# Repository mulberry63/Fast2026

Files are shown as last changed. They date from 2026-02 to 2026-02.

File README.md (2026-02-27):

# 🚁 Fast2026 - 中控杯

本项目旨在从零自主搭建一台具备自动导航与目标抓取能力的空中机器人（无人机），涵盖机械设计、硬件装配、ROS底层驱动与上层状态机算法。

---

## 🎯 项目核心任务分解

### 1. 🛠️ 无人机基础装配与试飞
- [ ] 根据装配文档（见 `docs/` 目录）完成飞机底盘拼装。
- [ ] 飞控参数配置，实现稳定可靠的手动遥控飞行。

### 2. 📡 机载设备部署与自动导航
- [ ] 挂载激光雷达与机载电脑。
- [ ] 烧录现有程序与环境配置。
- [ ] 实现无人机点到点的自主导航飞行。

### 3. ⚙️ 机械夹爪自主设计
- [ ] 根据抓取目标物，完成夹爪的 3D CAD 建模。

### 4. 🔌 夹爪舵机驱动开发
- [ ] 编写底层的舵机控制代码。
- [ ] 封装为 ROS 节点，实现通过 ROS 话题/服务控制夹爪开闭。

### 5. 🧠 系统集成与总控状态机
- [ ] 将夹爪节点接入现有 ROS 导航工作空间。
- [ ] 编写总控状态机

---

## 💻 团队协作指南 (Git 工作流)

为了避免文件冲突和代码丢失，请团队成员严格遵循以下步骤：

### 📥 1. 初次下载仓库 (Clone)
如果你是第一次参与项目，请打开终端（或 CMD）将云端代码下载到本地：
```bash
git clone https://github.com/你的用户名/Fast2026.git
```

### 🔄 2. 每日干活铁律 (Pull)
**⚠️ 警告：每次开始修改文件或写代码前，第一件事永远是更新代码！**
在 `Fast2026` 文件夹下打开终端，运行：
```bash
git pull
```

### 📤 3. 提交你的工作成果 (Add / Commit / Push)
当你在本地完成了某个文档修改、CAD模型更新或代码编写后，执行以下“三板斧”上传到云端：

```bash
# 第一步：把所有修改过、新增的文件暂存起来 (注意 add 后面的空格和点)
git add .

# 第二步：写下本次更新的备注留言 (请简明扼要，如"新增夹爪V1版打印文件")
git commit -m "在这里写你的修改备注"

# 第三步：推送到云端仓库
git push
```

---
**💡 小贴士：**
* 机械组同学提交 CAD 模型时，请**务必同时导出 STL/STEP 格式**，方便未安装 CAD 软件的同学预览。
* 代码组同学在 `ros_ws/` 中写代码时，**绝对不要**把 `build/` 和 `devel/` 文件夹传上来（项目已配置好 `.gitignore` 自动屏蔽）。
```

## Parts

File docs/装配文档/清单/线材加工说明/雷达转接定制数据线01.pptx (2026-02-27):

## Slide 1

SH1.0-12p -> GH1.25-4p雷达网线 适用DM载板v1.1-fast雷达转接板

SH1.0mm 12Pin 端

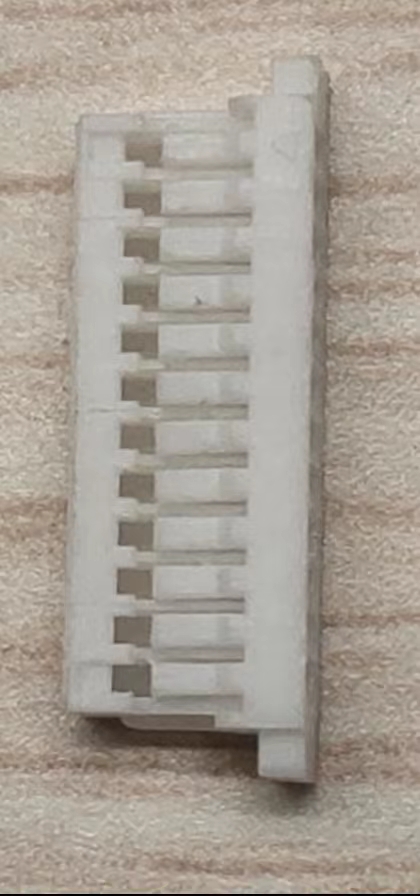
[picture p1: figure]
SH1.0mm 12P 胶壳

GH1.25mm 4Pin 端

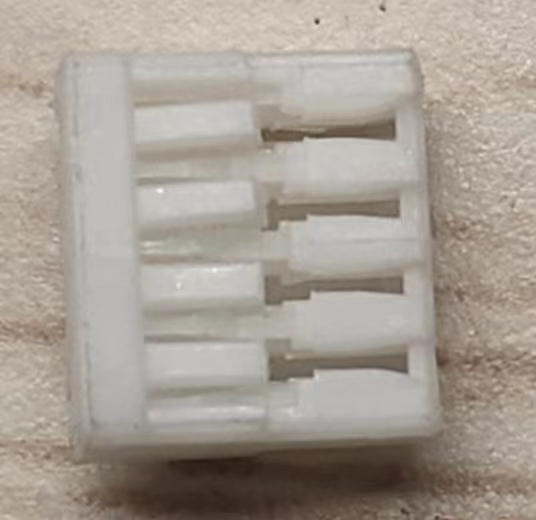
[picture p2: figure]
GH1.25mm 1x4P 压线端子胶壳

线长15cm，线材使用软硅胶线，线色如图 ，30根

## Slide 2

SH1.0-8p -> GH1.25-4p雷达网线 适用DM载板v2.0-fast雷达转接板

SH1.0mm 8Pin 端

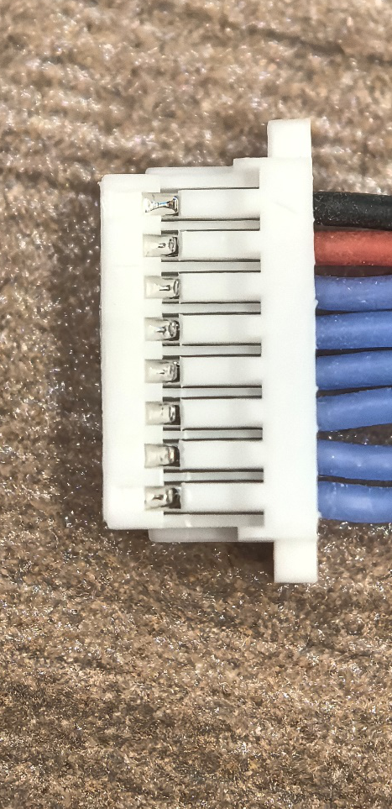
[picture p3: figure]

GH1.25mm 4Pin 端

线长15cm，线材使用软硅胶线，线色如图

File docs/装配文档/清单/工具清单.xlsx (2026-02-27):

序号 | 名称 | 规格 | 备注（如有，特殊要求） | 下单链接
1 | 航空箱 | 定制 |  | https://item.taobao.com/item.htm?from=cart&id=655358936203&skuId=4909482691266
2 | 拉杆工具箱 | 品牌同款拉杆箱大号-绿色 四层工具板 |  | https://item.taobao.com/item.htm?from=cart&id=709059705581&skuId=5535688010904
3 | 批头 | GSH025S 2.5x65mm内六角 |  | https://item.taobao.com/item.htm?id=596181686009&from=cart&skuId=4309524610184
4 | 批头 | GS5P-32 150mm长5支装 |  | https://item.taobao.com/item.htm?id=596181686009&from=cart&skuId=4309524610203
5 | 批头 | GS5P-31 65mm长5支装 |  | https://item.taobao.com/item.htm?id=596181686009&from=cart&skuId=4309524610202
6 | 批头 | GSH015S 1.5x65mm内六角 |  | https://item.taobao.com/item.htm?id=596181686009&from=cart&skuId=4309524610183
7 | RC遥控模型车内六角螺丝刀十字一字六角套筒6.35mm航模工具套装 (https://item.taobao.com/item.htm?id=762095687046&from=cart&skuId=5249389084331) | 内六角4合一套装 |  | https://item.taobao.com/item.htm?id=762095687046&from=cart&skuId=5249389084331
8 | SATA世达棘轮扳手套筒组合套装小飞/中飞/大飞汽修车工具专用全套 (https://item.taobao.com/item.htm?id=782432810657&from=cart&skuId=5512006822639) | 小飞套筒组套【36件】09001 |  | https://item.taobao.com/item.htm?id=782432810657&from=cart&skuId=5512006822639
9 | 开拓迷你开口梅花两用扳手套装组合大全小号螺母全英制一整成套 (https://item.taobao.com/item.htm?id=540861523658&from=cart&skuId=4961793017982) | 公制开口梅花迷你5件套（4-4.5-5-5.5-6mm） |  | https://item.taobao.com/item.htm?id=540861523658&from=cart&skuId=4961793017982
10 | 超薄款双头开口扳手 | 超薄款梅开两用扳手4mm |  | https://detail.tmall.com/item.htm?id=851356332552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
11 | 博世手动螺丝刀46件26件套棘轮内六角套筒十字螺丝批组合工具套装 (https://item.taobao.com/item.htm?id=763569830538&from=cart&skuId=5258953145313) | 26件套棘轮扳手批头 |  | https://item.taobao.com/item.htm?id=763569830538&from=cart&skuId=5258953145313
12 | 日本福冈内六角套装s2加长款6角梅花螺丝刀小t型折叠六棱扳手工具 (https://item.taobao.com/item.htm?id=676218849401&from=cart&skuId=4857481332285) | FO-3301A【中长球头平头9件套】 性价比推荐 |  | https://item.taobao.com/item.htm?id=676218849401&from=cart&skuId=4857481332285
13 | 电钻 | 棘轮冲击款【2.0Ah两电一充】+全套礼包 |  | https://item.taobao.com/item.htm?id=728453365825&from=cart&skuId=5823571047206
14 | 世达螺丝刀十字一字小高硬度工具梅花起子小型平口改锥带强磁套装 (https://item.taobao.com/item.htm?id=759865044572&from=cart&skuId=5407968842822) | 【十字】3x75mm/62302 |  | https://item.taobao.com/item.htm?id=759865044572&from=cart&skuId=5407968842822
15 | 世达螺丝刀十字一字小高硬度工具梅花起子小型平口改锥带强磁套装 | 【一字】3x75mm/62202 |  | https://item.taobao.com/item.htm?id=759865044572&from=cart&skuId=5407968842823
16 | 美国EDS-110991 公制内六角工具套裝 4支1.5 2.0 2.5 3.0X120现货 (https://item.taobao.com/item.htm?id=522870804348&from=cart&skuId=3171451899987) | 整套4把（EDS-110991） |  | https://item.taobao.com/item.htm?id=522870804348&from=cart&skuId=3171451899987
17 | 镊子 | 【安立信】高精密不锈钢 六件套（AT-10、11、12、13、14、15）送收纳盒 |  | https://detail.tmall.com/item.htm?from=cart&id=854938114743&skuId=5999010703984
18 | 日本福冈水口钳偏口钳子模型小剪钳口水剪德国进口电工专用斜口钳 (https://item.taobao.com/item.htm?id=572377244946&from=cart&skuId=3968092274861) | 7寸水口钳FO-1117 |  | https://item.taobao.com/item.htm?id=572377244946&from=cart&skuId=3968092274861
19 | 鹏工薄壁外六角套筒螺丝刀电脑组装薄套筒起子外六角螺母深套筒批 (https://item.taobao.com/item.htm?id=585503044239&from=cart&skuId=4138388982041) | 5.5mm单支 |  | https://item.taobao.com/item.htm?id=585503044239&from=cart&skuId=4138388982041
20 | 鹏工薄壁外六角套筒螺丝刀电脑组装薄套筒起子外六角螺母深套筒批 (https://item.taobao.com/item.htm?id=585503044239&from=cart&skuId=4138388982042) | 4.0mm单支 |  | https://item.taobao.com/item.htm?id=585503044239&from=cart&skuId=4138388982042
21 | 钢拓活动棘轮扳手快速扳手双头双向梅花开口汽修活头两用扳手工具 (https://item.taobao.com/item.htm?id=574692714560&from=cart&skuId=5802478869891) | 13mm活动棘轮 |  | https://item.taobao.com/item.htm?id=574692714560&from=cart&skuId=5802478869891
22 | 钢拓活动棘轮扳手快速扳手双头双向梅花开口汽修活头两用扳手工具 (https://item.taobao.com/item.htm?id=574692714560&from=cart&skuId=5802478869899) | 8mm活动棘轮 |  | https://item.taobao.com/item.htm?id=574692714560&from=cart&skuId=5802478869899
23 | 绿林水口钳高达模型剪钳斜口钳口水钳日本德国电工进口线偏口钳子 (https://item.taobao.com/item.htm?id=636927035616&from=cart&skuId=4792100687124) | 【匠心质造】5寸日式水口钳-超薄款【模型推荐】 |  | https://item.taobao.com/item.htm?id=636927035616&from=cart&skuId=4792100687124
24 | 绿林针嘴钳尖嘴钳电工专用小钳子大全尖头钳多功能尖嘴钳子手工用 (https://item.taobao.com/item.htm?id=732723065228&from=cart&skuId=5069822680654) | 迷你针嘴钳150mm |  | https://item.taobao.com/item.htm?id=732723065228&from=cart&skuId=5069822680654
25 | 绿林L型套筒扳手工具六角烟斗7字型弯头双头穿孔轮胎扳手6-19mm (https://item.taobao.com/item.htm?id=558244068545&from=cart&skuId=4819402215447) | 加长L型扳手13mm |  | https://item.taobao.com/item.htm?id=558244068545&from=cart&skuId=4819402215447
26 | 绿林针嘴钳尖嘴钳电工专用小钳子大全尖头钳多功能尖嘴钳子手工用 (https://item.taobao.com/item.htm?id=732723065228&from=cart&skuId=5069822680660) | 迷你尖嘴钳125mm |  | https://item.taobao.com/item.htm?id=732723065228&from=cart&skuId=5069822680660
27 | 绿林碳纤维卡尺高精度数显游标卡尺玻璃栅电子卡尺不锈钢数字测量 (https://item.taobao.com/item.htm?id=766044927383&from=cart&skuId=5268275533110) | 【0-150mm】【20年寿命玻璃栅款】【碳纤维升级】 |  | https://item.taobao.com/item.htm?id=766044927383&from=cart&skuId=5268275533110
28 | CFORCE便携显示器4k触控144hz扩展屏笔记本电脑副屏switch外接屏 (https://item.taobao.com/item.htm?id=605670886301&from=cart&skuId=5967632443268) | 15.6寸【120Hz办公16Plus】2.5K超清/IPS护眼/100%sRGB色域/送保护皮套 |  | https://item.taobao.com/item.htm?id=605670886301&from=cart&skuId=5967632443268
29 | 友邦焊锡丝 高纯度 流动性好 活性锡线Sn63PbA 63%含锡量 松香芯 (https://item.taobao.com/item.htm?id=43741015860&from=cart&skuId=79364921499) | Sn63PbA 1.0mm线径（净重100克） |  | https://item.taobao.com/item.htm?id=43741015860&from=cart&skuId=79364921499
30 | 日本福冈尖嘴钳进口 德国技术多功能尖头 尖咀钳6寸钓鱼钳子专用 (https://item.taobao.com/item.htm?id=521588031533&from=cart&skuId=3955094443294) | 2605欧式尖嘴钳8寸（送电笔） |  | https://item.taobao.com/item.htm?id=521588031533&from=cart&skuId=3955094443294
31 | 日本tajima田岛美工刀重型全钢加厚壁纸刀刀架 (https://item.taobao.com/item.htm?id=36632336125&from=cart&skuId=4914053270244) | 中号18mm款/旋钮锁 AC501B |  | https://item.taobao.com/item.htm?id=36632336125&from=cart&skuId=4914053270244
32 | 得力双头油性记号笔黑色勾线笔快干防水美术专用小学生防油不掉色 (https://item.taobao.com/item.htm?id=794834842303&from=cart&skuId=5426482581983) | 【黑色】双头12支 / 6823（1盒） |  | https://item.taobao.com/item.htm?id=794834842303&from=cart&skuId=5426482581983
33 | 剪刀 | 中号+大号/各1把黄色（发黑防锈） |  | https://item.taobao.com/item.htm?id=638671987627&from=cart&skuId=5046922966914
34 | VESSEL内六角批头日本进口威威六角批头加长电动圆头六方风批强磁 (https://item.taobao.com/item.htm?id=654440293673&from=cart&skuId=5695207560125) | 5孔批头夹（蓝色）(BH-05N) |  | https://item.taobao.com/item.htm?id=654440293673&from=cart&skuId=5695207560125
35 | 焊台 | 标配+3种烙铁头（T12-K头+T12-Ku头+T12-BC3头） |  | https://item.taobao.com/item.htm?id=609759063116&from=cart&skuId=5099730029461
36 | 日本福冈进口多功能钢丝钳老虎钳子拉线钳电工专用特种钢手钳德国 (https://item.taobao.com/item.htm?id=564658222984&from=cart&skuId=3641967885881) | FO-1302钢丝钳（7寸拉线款） |  | https://item.taobao.com/item.htm?id=564658222984&from=cart&skuId=3641967885881
37 | 日本福冈专用钢丝钳特种老虎钳多功能尖嘴钳工业级斜嘴钳电工套装 (https://item.taobao.com/item.htm?id=564165540337&from=cart&skuId=4580939465805) | FO-1304尖嘴钳【6寸】新款 |  | https://item.taobao.com/item.htm?id=564165540337&from=cart&skuId=4580939465805
38 | 绿联micro hdmi转hdmi线连接转接小头采集卡高清直播适用索尼相机 (https://item.taobao.com/item.htm?id=37607334919&from=cart&skuId=5607363026888) | 【稳定转换高清大屏】4K/60Hz高清-加厚PVC，1.5米 |  | https://detail.tmall.com/item.htm?from=cart&id=37607334919&skuId=5607363026888
39 | 绿联拓展坞typec扩展hdmi投屏转换usb分线器hub集线网线多接口转接头适用华为苹果雷电4笔记本电脑iPad11平板 | 【4合1】USB3.0x3+千兆网口 |  | https://detail.tmall.com/item.htm?from=cart&id=628685171247&skuId=5324107194639
40 | 扎带 | 15公分长丨白色细款丨100根/包 |  | https://item.taobao.com/item.htm?id=729697526781&from=cart&skuId=5920985002019
41 | HDMI接口to转 Mini Micro 高清 单反 相机 监视器 4K 弹簧线 短线 (https://item.taobao.com/item.htm?id=599378064489&from=cart&skuId=4529987314852) | 【4K 极细版】HDMI转D型（Micro HDMI） 直对直 |  | https://detail.tmall.com/item.htm?from=cart&id=599378064489&skuId=4529987314852
42 | 德力西电气145合一精工螺丝刀组套设备拆装S2+CRV钢强磁吸附套装 (https://item.taobao.com/item.htm?id=846600045464&from=cart&skuId=5627821992278) | 145合一螺丝刀套装 |  | https://item.taobao.com/item.htm?id=846600045464&from=cart&skuId=5627821992278
43 | 黑色醋酸胶带耐高温绝缘胶带排线束捆扎手机电视屏幕液晶维修胶布 (https://item.taobao.com/item.htm?id=38441542800&from=cart&skuId=51831447403) | 30MM宽*30M长 |  | https://item.taobao.com/item.htm?id=38441542800&from=cart&skuId=51831447403
44 | 黑色醋酸胶带耐高温绝缘胶带排线束捆扎手机电视屏幕液晶维修胶布 (https://item.taobao.com/item.htm?id=38441542800&from=cart&skuId=51831447403) | 20MM宽*30M长常用款 |  | https://item.taobao.com/item.htm?id=38441542800&from=cart&skuId=51831447399
45 | 12V 6A 72W电源适配器24v 5A 100W适合B6 Q6 M6 M7平衡充电器供电 (https://item.taobao.com/item.htm?id=44358580335&from=cart&skuId=4783448933220) | 12V 6A【DC5.5插头】安全功率60W |  | https://item.taobao.com/item.htm?id=44358580335&from=cart&skuId=4783448933220
46 | Updown露营车手推车营地拖车户外可折叠野营小拉车野餐车儿童可躺 (https://item.taobao.com/item.htm?id=735036772871&from=cart&skuId=5871039130680) | ⭐店长推荐【坦克款/曜石黑】+升级可折叠桌板 |  | https://item.taobao.com/item.htm?id=735036772871&from=cart&skuId=5871039130680
47 | XT60 XT30 T插母头转DC5.5*2.1/2.5mm母头视频眼镜电池充电转接线 (https://item.taobao.com/item.htm?id=831186088302&from=cart&skuId=5568304736538) | DC5.5*2.5母转XT30母 |  | https://item.taobao.com/item.htm?id=831186088302&from=cart&skuId=5568304736538
48 | 3m双面胶贴强力粘胶海绵胶带汽车车用VHB防水无痕高粘度固定墙面 (https://item.taobao.com/item.htm?id=592230232424&from=cart&skuId=5249613279075) | 【升级 2卷】1厘米宽*3米 |  | https://item.taobao.com/item.htm?id=592230232424&from=cart&skuId=5249613279075
49 | 3m双面胶贴强力粘胶海绵胶带汽车车用VHB防水无痕高粘度固定墙面 (https://item.taobao.com/item.htm?id=592230232424&from=cart&skuId=4252197123714) | 3厘米宽*3米长【升级版】 |  | https://item.taobao.com/item.htm?id=592230232424&from=cart&skuId=4252197123714
50 | 扎带 | 3*200宽2.5白100条 |  | https://item.taobao.com/item.htm?id=839224689390&from=cart&skuId=5600725460192
51 | 扎带 | 3*100宽2.5黑100条 |  | https://item.taobao.com/item.htm?id=839224689390&from=cart&skuId=5600725460186
52 | 德力西万用表电工专用维修数字高精度万能表全自动智能防烧890D/C (https://item.taobao.com/item.htm?id=709886959523&from=cart&skuId=4975474060765) | 890D+升级【赠鳄鱼夹+电池+表笔+保险管】 |  | https://item.taobao.com/item.htm?id=709886959523&from=cart&skuId=4975474060765
53 | 卡夫特502GP胶水正品瞬干胶粘金属铁塑料快干速干多功能粘得牢瞬间胶粘鞋补鞋专用焊接剂强力万能胶水 | 502GP 2支【划算】 |  | https://item.taobao.com/item.htm?id=584458030809&from=cart&skuId=5529823123973
54 | SMA小辣椒GPS1.2Ｇ1.4Ｇ1.5G-5Ｇ5.8ＧHz315mhz433/GPS/4G/5G天线 | SMA直黑套 公头内针 | 拍下备注 频率1410mhz-1470mhz | https://item.taobao.com/item.htm?abbucket=17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
55 | MMCX转SMA馈线 | MMCX弯头转SMA内孔，100mm长 |  | https://item.taobao.com/item.htm?from=cart&id=615078294038&skuId=4501459182444
56 | 德力西强力吸锡器吸锡泵电子拆焊清除锡渣焊锡工具手动真空吸锡枪 | 【紧密自动回弹款单支装】半铝强力吸锡器（防静电+耐高温） |  | https://item.taobao.com/item.htm?id=765881479108&from=cart&skuId=5267752237089
57 | 德力西钢卷尺5米家用不锈钢米尺高精度圈尺加厚加硬拉尺10米尺子 (https://item.taobao.com/item.htm?id=704061414618&from=cart&skuId=4957646261617) | 【德力西】7.5米*25mm加宽尺带-不锈钢尺带-激光刻度 |  | https://item.taobao.com/item.htm?id=704061414618&from=cart&skuId=4957646261617
58 | 德力西棘轮扳手快速梅花开口自动双向万能两用梅开板手工具套装 (https://item.taobao.com/item.htm?id=682984862384&from=cart&skuId=4883045608286) | 德力西加长-13mm【用坏换新】送手套 |  | https://item.taobao.com/item.htm?id=682984862384&from=cart&skuId=4883045608286

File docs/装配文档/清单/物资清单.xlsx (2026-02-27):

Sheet: Sheet1
物资清单
序号 | 名称 | 数量 | 购买链接 | 备注
 | 碳板 | 1 |  | 图纸和加工说明见碳板文件夹
 | 雷达保护罩 | 1
 | livox mid 360 | 1
 | 微空飞塔（nxtpx4+50A） | 1 | https://e.tb.cn/h.6zjjxA4rLb3XZSN?tk=lh0YVpP3kD9 CZ225
 | 电池（21700-6s1p） | 2 | 定制21700 40T大功率航模植保机飞行机25.2v6S1P动力锂电池组-淘宝网 (https://item.taobao.com/item.htm?app=chrome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)
 | 分电板 | 1
 | 7037桨叶（PC桨叶 乾丰7037） | 4 | https://item.taobao.com/item.htm?abbucket=20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
 | BB响 | 1 | 电池航模遥控飞机1-8S高精度电量显示器低压报警器双功能BB响电显-淘宝网 (https://item.taobao.com/item.htm?ali_trackid=282_6f4573d720882b9794d1c7404aa6e142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)
 | 接收器 | 1 | https://item.taobao.com/item.htm?id=615817018031&skuId=5969046851703
 | AT9SPRO遥控器 | 1 | 乐迪 AT9S 航模遥控器多轴直升机固定翼PRO无人机2.4G中文模型AT9-淘宝网 (taobao.com) (https://item.taobao.com/item.htm?detail_redpacket_pop=true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)
 | 遥控器电池 | 1 | 乐迪AT9S/AT10/天地飞9遥控器控电 3s 11.1v 2200mAh 8C锂电池-淘宝网 (taobao.com) (https://item.taobao.com/item.htm?_u=a20mja9h57be&id=529555323423&skuId=3472562656133)
 | 优象光流（UP-T101-Plus-PX4） | 1 | UP-T101-Plus光流模块激光测距一体模组4米激光-淘宝网 (taobao.com) (https://item.taobao.com/item.htm?from=cart&id=737685317693&skuId=5486536996319)
 | NX核心板 |  | Jetson Orin NX 16GB 模组 核心板 orin nano agx orin Xavier-tmall.com天猫 (https://detail.tmall.com/item.htm?from=cart&id=699184482674&skuId=5113558482139)
 | NX散热大风扇 | 1 | https://e.tb.cn/h.6BrOpWUDVmbMGot?tk=A6gvVLE5WGd HU287
 | 网卡天线 |  | 2.4g wifi内置FPC软天线5G 5.8G双频PCB贴片ZigBee蓝牙全向高增益-淘宝网 (https://item.taobao.com/item.htm?from=cart&id=586127342811&skuId=4017577965391)
 | 达妙V2载板+256G硬盘+网卡 | 1 | https://e.tb.cn/h.6BG78LJdOkJnq3O?tk=FqsiVLEaQj8 CZ321
 | USB相机90度 uvc相机 90°视场角无畸变 3.24mm焦距 30fps-120fps | 1 | 200万像素1080P高清USB摄像头模组120帧高帧率UVC免驱动鱼眼广角-tmall.com天猫 (https://detail.tmall.com/item.htm?app=chrome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)
 | USB相机120度（uvc相机 120°视场角微畸变 1.8mm焦距 30fps-120fps） | 1 | 200万像素1080P高清USB摄像头模组120帧高帧率UVC免驱动鱼眼广角-tmall.com天猫 (https://detail.tmall.com/item.htm?app=chrome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)
 | Tmotor f90 1300kv | 4 | https://item.taobao.com/item.htm?abbucket=20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
 | 螺丝M3*14（50个） | 2 | https://item.taobao.com/item.htm?id=598485951777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
 | 单头铝柱M3*18+4 (10个) | 1 | https://detail.tmall.com/item.htm?from=cart&id=798703064988&skuId=5617287975848
 | 铝柱M3*20（5个） | 2 | https://detail.tmall.com/item.htm?from=cart&id=719358549398&skuId=5189006551294
 | 铝柱M3*30（5个） | 2 | https://detail.tmall.com/item.htm?from=cart&id=719358549398&skuId=5189006551294
 | 螺丝M2*8 | 1 | https://detail.tmall.com/item.htm?id=631928248397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
 | 螺丝M2*6 | 1 | https://detail.tmall.com/item.htm?id=631928248397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
 | 螺丝M3*6 | 1 | 黑色304不锈钢螺丝钉带螺母大全套装十字圆头小螺钉M2M3M4M5M6MM-tmall.com天猫 (https://detail.tmall.com/item.htm?abbucket=20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)
 | 螺丝M3*5 | 1 | M3M4M5M6 304不锈钢黑色圆头盘头内六角螺丝螺母套装组合大全GG-tmall.com天猫 (https://detail.tmall.com/item.htm?abbucket=20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)

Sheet: Sheet2
序号

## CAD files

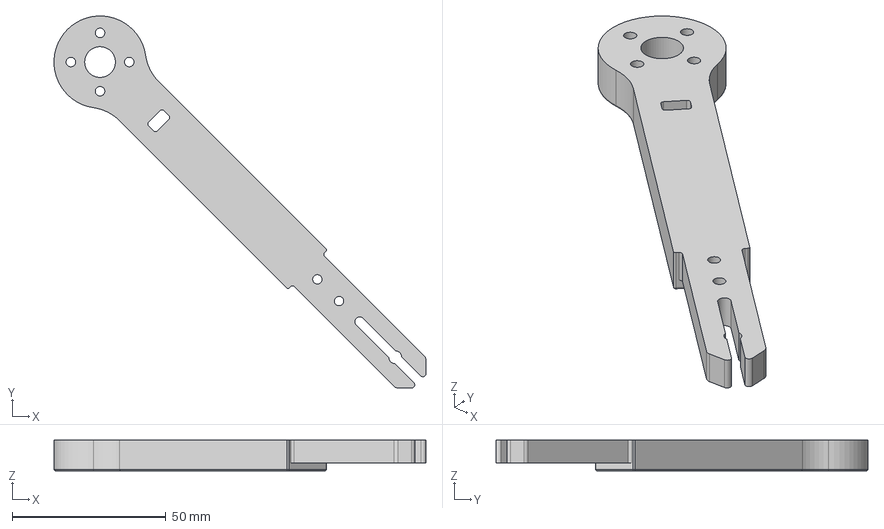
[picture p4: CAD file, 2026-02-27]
docs/装配文档/碳板/carbon_cnc0224/机臂300 v2.step
121.0 x 121.0 x 10.0 mm

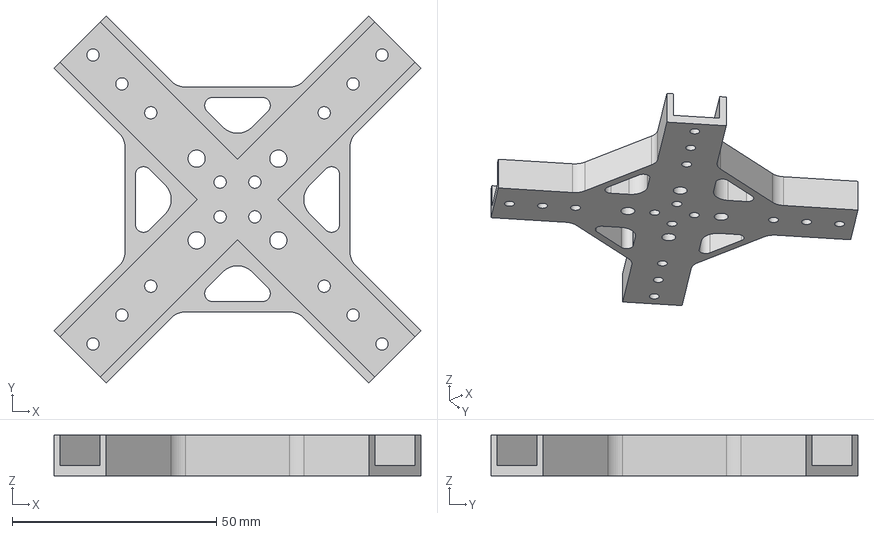
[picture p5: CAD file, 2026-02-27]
docs/装配文档/碳板/carbon_cnc0224/机架下中心板 v2.step
89.8 x 89.8 x 9.98 mm

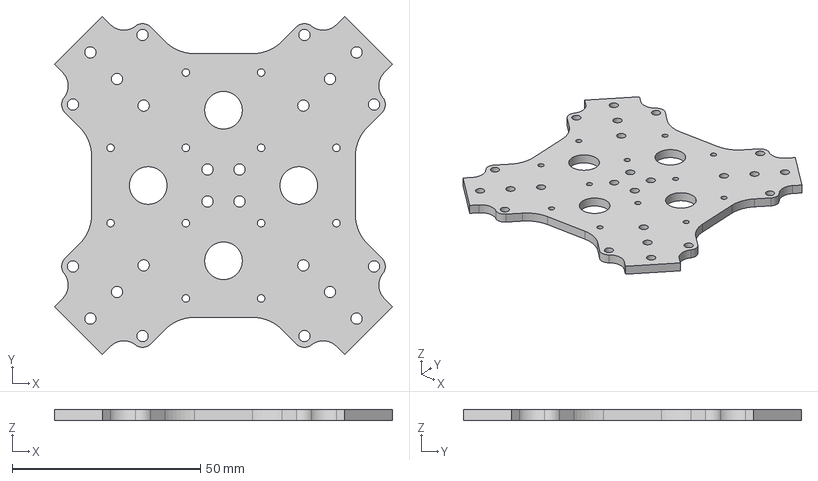
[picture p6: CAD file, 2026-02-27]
docs/装配文档/碳板/carbon_cnc0224/机架上中心板 v3.step
89.8 x 89.8 x 3.00 mm

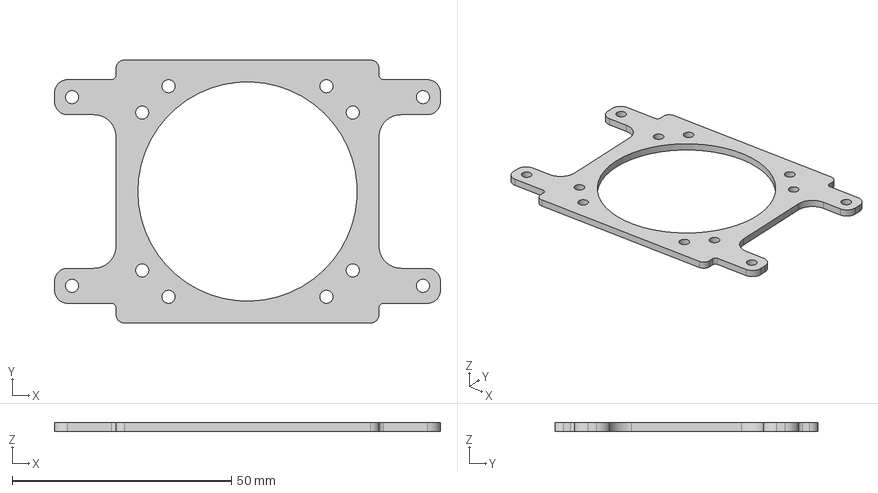
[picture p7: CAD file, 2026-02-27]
docs/装配文档/碳板/carbon_cnc0224/mid360雷达固定板 v2.step
88.0 x 60.0 x 2.00 mm

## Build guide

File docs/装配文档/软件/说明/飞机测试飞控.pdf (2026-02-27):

# 618飞机测试飞控

打开终端，此时会在618test目录中

输入sudo chmod 777 /dev/tty*给权限

之后输入roslaunch mavros px4.launch

最后输出CMD：Unexpected 。。。。。说明飞控与NX连接正常

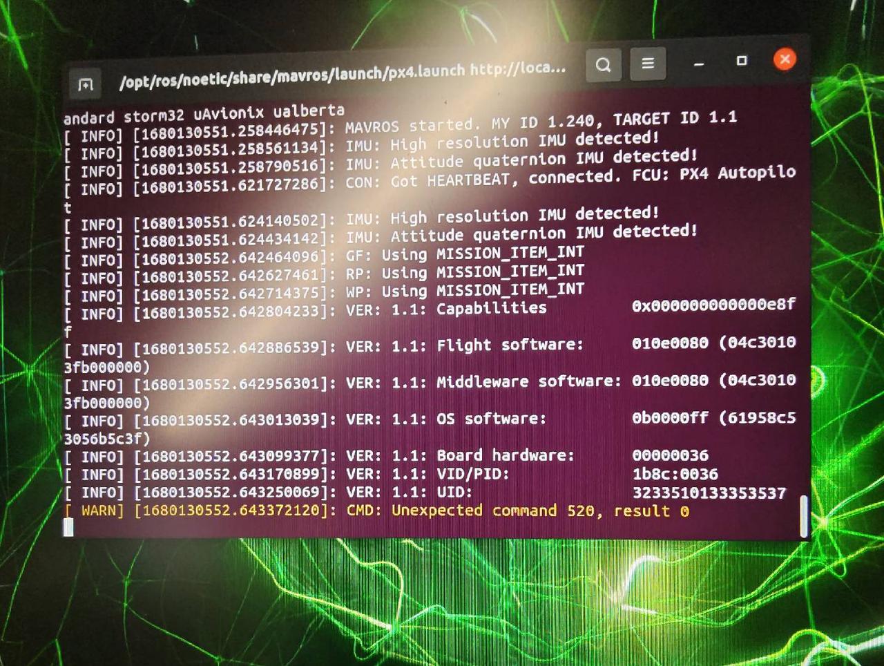
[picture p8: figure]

rostopic echo /mavros/imu/data_raw来查看imu是否有数据

Rostopic echo /mavros/px4flow/raw/optical_flow_rad来查看光流数据

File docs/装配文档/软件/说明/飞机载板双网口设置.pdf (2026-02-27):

# 618飞机载板双网口设置

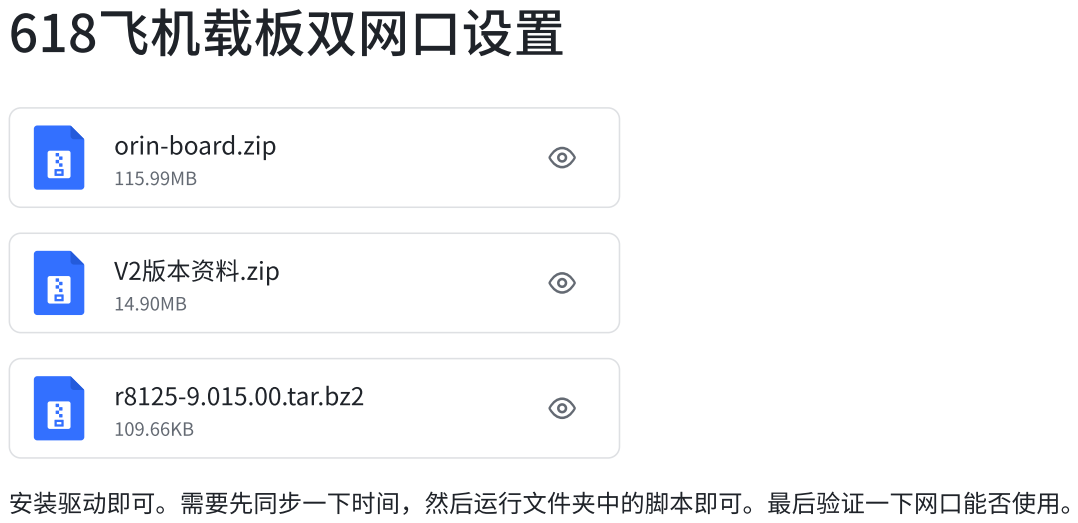
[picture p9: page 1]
V2版本资料.zip; r8125-9.015.00.tar.bz2

orin-board.zip

安装驱动即可。需要先同步一下时间，然后运行文件夹中的脚本即可。最后验证一下网口能否使用。

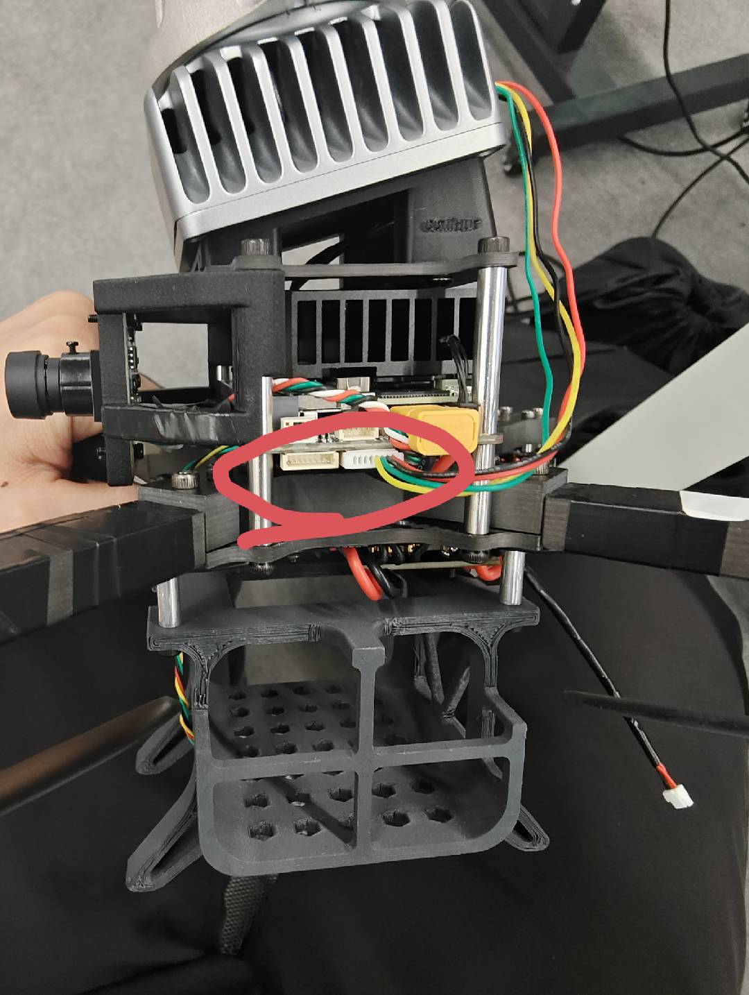
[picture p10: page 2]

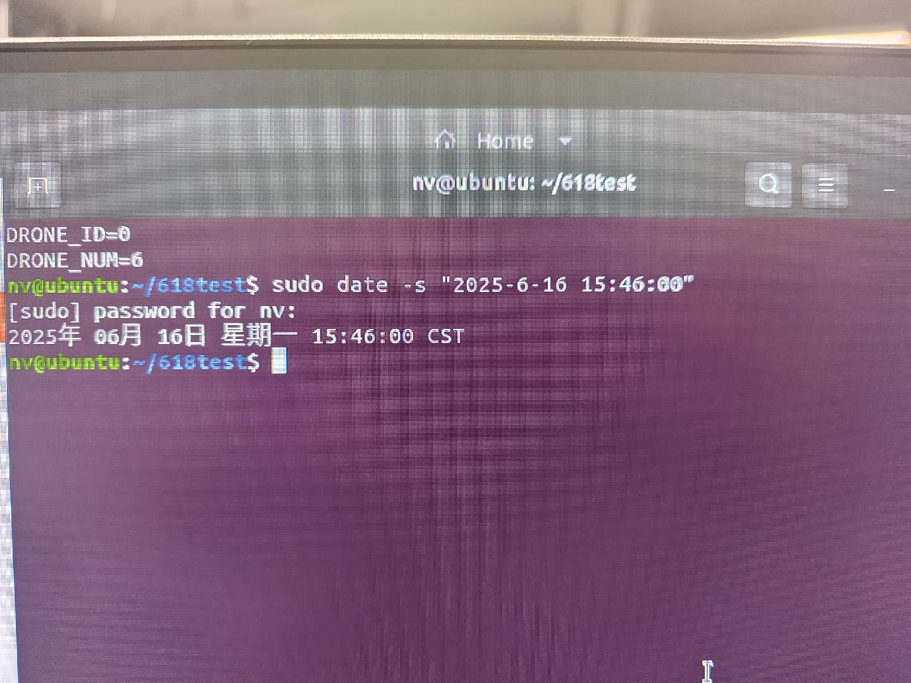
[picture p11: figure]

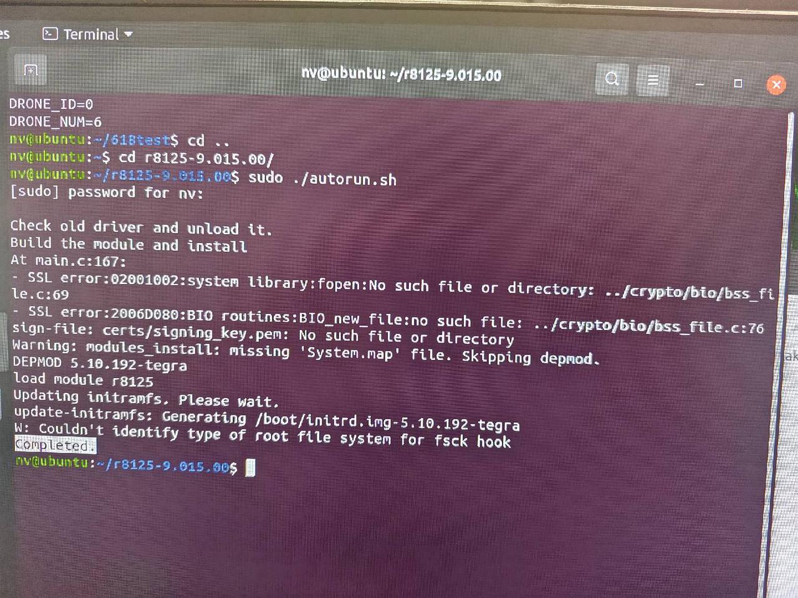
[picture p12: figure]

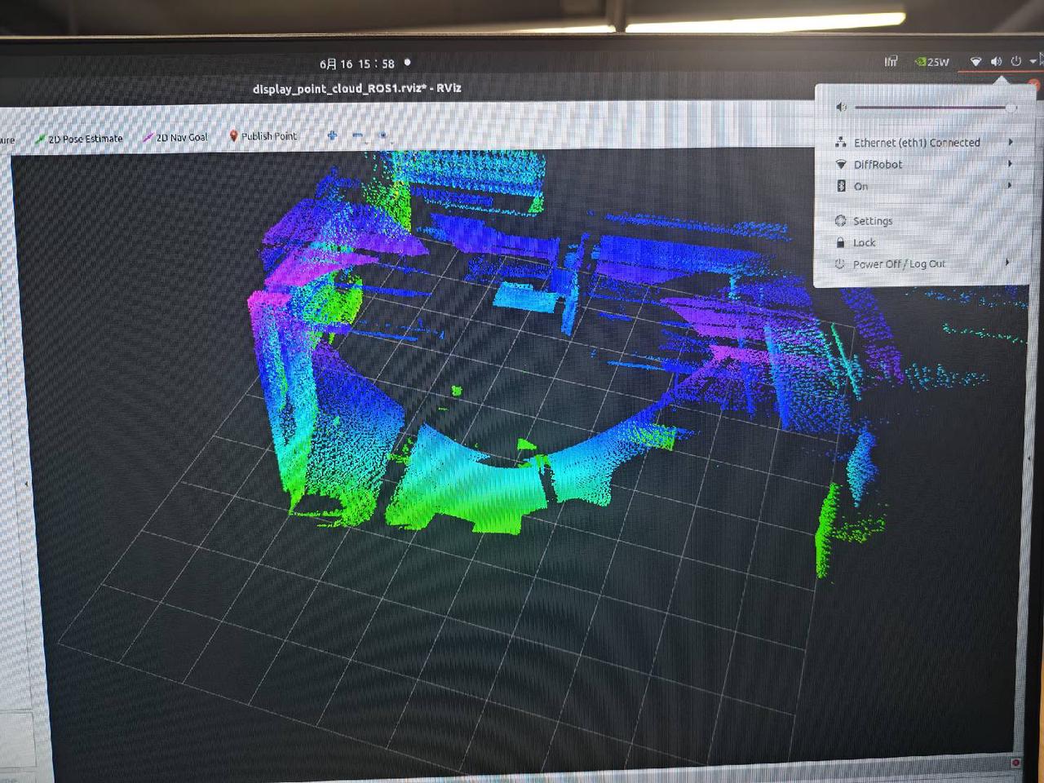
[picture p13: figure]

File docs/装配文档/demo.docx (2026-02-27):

1、 检查代码
1、 检查px4代码中IP等内容是否正确，NX和飞控通过有线连接，再由另一台设备通过nomachine与NX连接
2、 检查膨胀系数与栅格大小是否符合要求，视后续飞场测试情况进行调整
2、 准备阶段
1、 检查电机转向是否正确，桨正反是否正确，电池电量是否充足
2、 将飞机拿入飞场，确保遥控器安全后上电
3、 将飞机与场地x轴正方向对齐后方可进入rviz界面，若出现偏差需要重新起代码

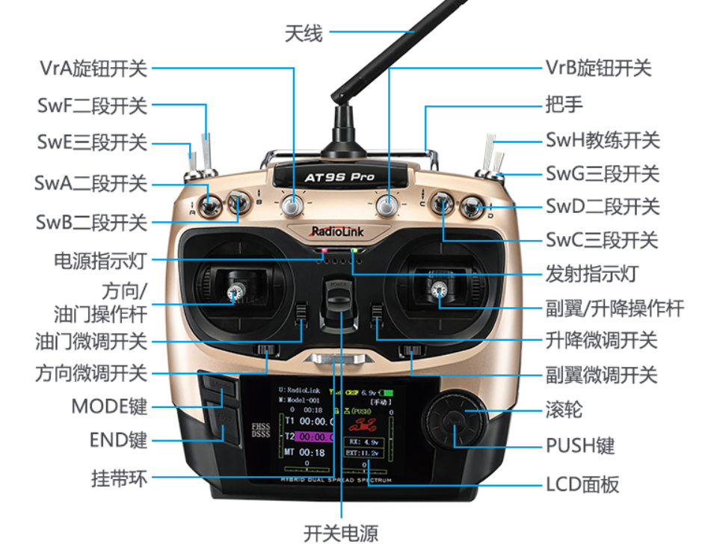
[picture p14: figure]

4、 检查遥控器设置，SwD拨在下方能收到外界指令以执行代码；SwE拨在下方，能接受指令并且为pisition模式；SwA在上方，确保arm没解锁；油门回中；SwF是kill，确保前面设置好以后将其拨到下方
3、 起代码
1、 准备工作：在一台linux系统的电脑上先通过预设好的框架，使用ssh连接到NX，然后在展示的大屏幕电脑上通过nomachine连接到nx
2、 先把所有需要的代码敲入终端，包括run_demo.sh（linux），0214vis_run.sh（大屏幕），takeoff.sh（linux），land.sh（linux）
3、 起整合好的脚本，run_demo.sh，里面包含有mavros、lidar、fast-lio等内容
4、 在大屏幕上启动0214vis，检查右下角fps是否正常，及是否有雷达点云图像；也可以在linux上起check_odom.sh检查定位是否存在偏差
5、 确保遥控器正确设置后，启动takeoff.sh，注意在起代码前与拿遥控器的沟通好
6、 在大屏幕上选择3D goal进行给点飞行，注意不要给到场地外的点，也尽量不要给距离过长的点
7、 在飞行完成以后回到起飞的位置，启动land.sh以降落（若代码无响应需手动降落，详见飞行过程中的处理）
4、 飞行过程中的处理
1、 飞行过程中碰撞到障碍物（低速），定位没有炸，想要无人机停下来不继续飞：将SwD拨到上面，此时无人机不再接受电脑指令，然后将油门稍稍向下拨，等无人机触地以后将油门归零，然后kill
2、 飞行过程中碰撞到障碍物（低速），定位炸了：情况紧急直接kill掉；不紧急则将SwD拨到上面，此时无人机不再接受电脑指令，然后将油门稍稍向下拨，等无人机触地以后将油门归零，然后kill
3、 飞行过程中出现情况需要停止接收代码并悬停（较高速）：将SwD拨到上面，此时遥控器控制为机体坐标系，需要根据无人机此时的速度给予反方向的调整帮助其停止下来进入悬停
4、 接受代码的情况下需要微调位置：此时遥控器控制为世界坐标系，根据世界坐标系下xyz轴方向进行调整
5、 场地布置
1、 确保障碍物之间有足够的距离，保障无人机能够正常通过
2、 尤其注意直径一米的圆或边长一米的正方形，确保无人机的膨胀系数和栅格大小能使其顺利通过
3、 雷达视角为-15°~40°，故无法检测到下方近距离的障碍物，在避障过程中可能会因上方有障碍物导致其向下飞行进行躲避从而装上障碍物，因此场地布置中也需要注意

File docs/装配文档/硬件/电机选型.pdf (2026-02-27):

电机型号选取，需考虑整机重量以及续航时间，结合电池参数与桨叶型号，综合选取，部分 电机力效表如下：

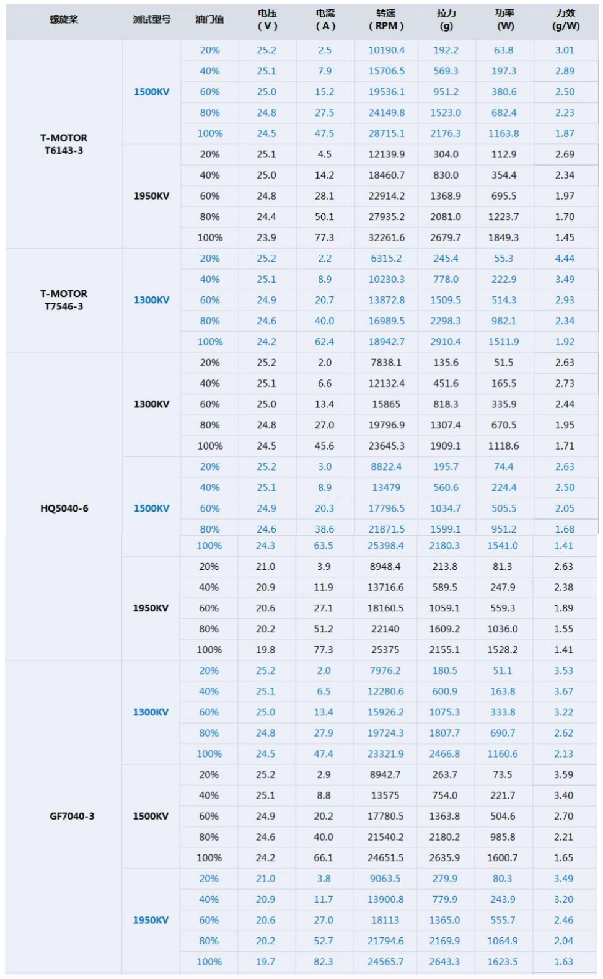
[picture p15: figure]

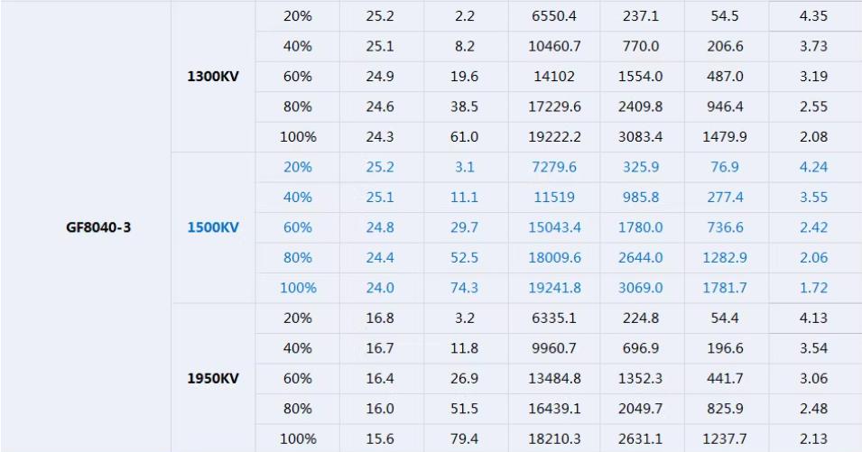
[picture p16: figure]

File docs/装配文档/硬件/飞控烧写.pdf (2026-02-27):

# 618飞机飞控烧写

### ①.按住BOOT按键上电，打开STM32CubeProgrammer

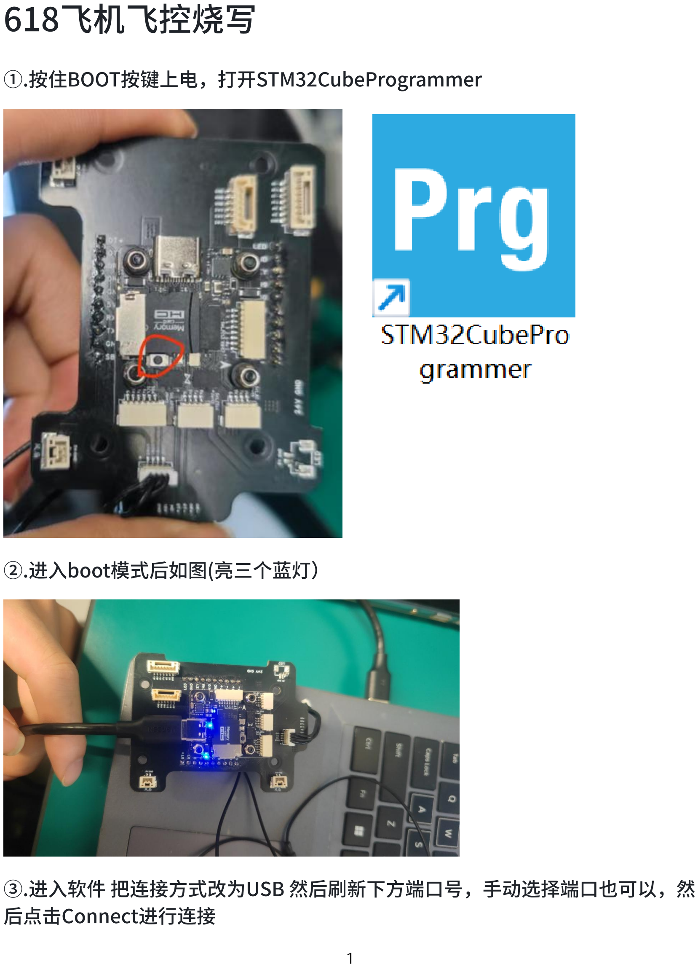
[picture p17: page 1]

②.进入boot模式后如图(亮三个蓝灯）

③.进入软件 把连接方式改为USB 然后刷新下方端口号，手动选择端口也可以，然

### 后点击Connect进行连接

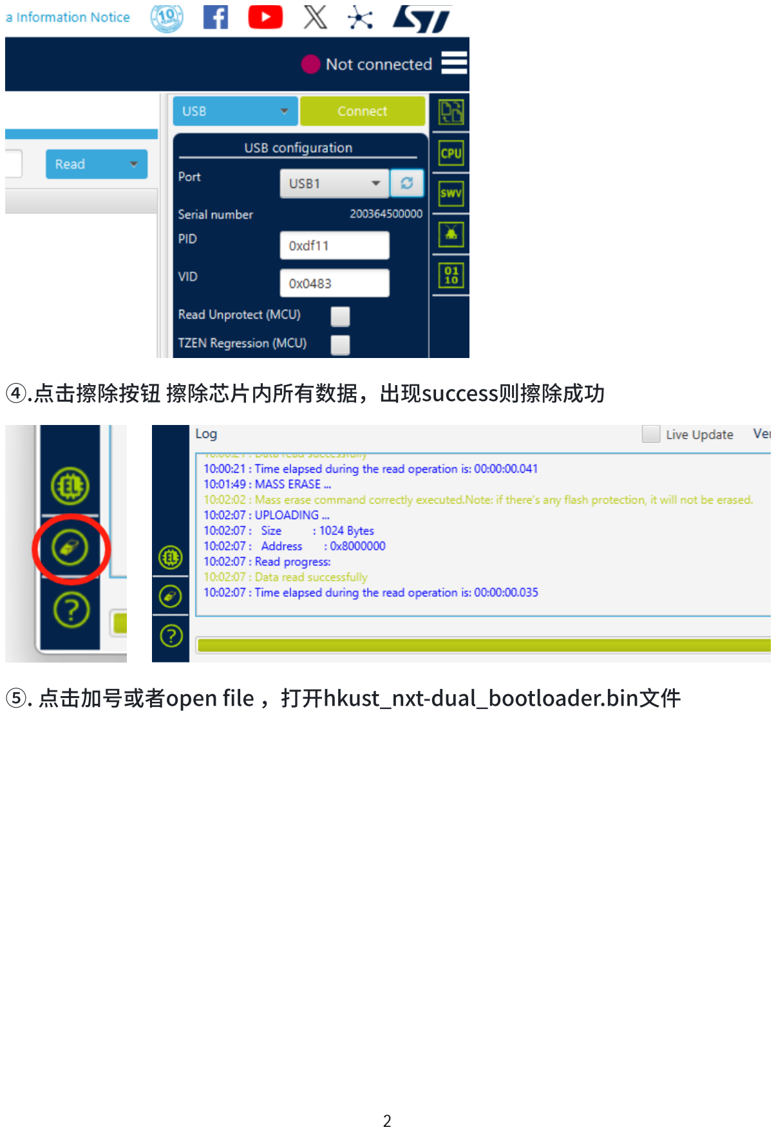
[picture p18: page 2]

④.点击擦除按钮 擦除芯片内所有数据，出现success则擦除成功

### ⑤. 点击加号或者open file ，打开hkust_nxt-dual_bootloader.bin文件

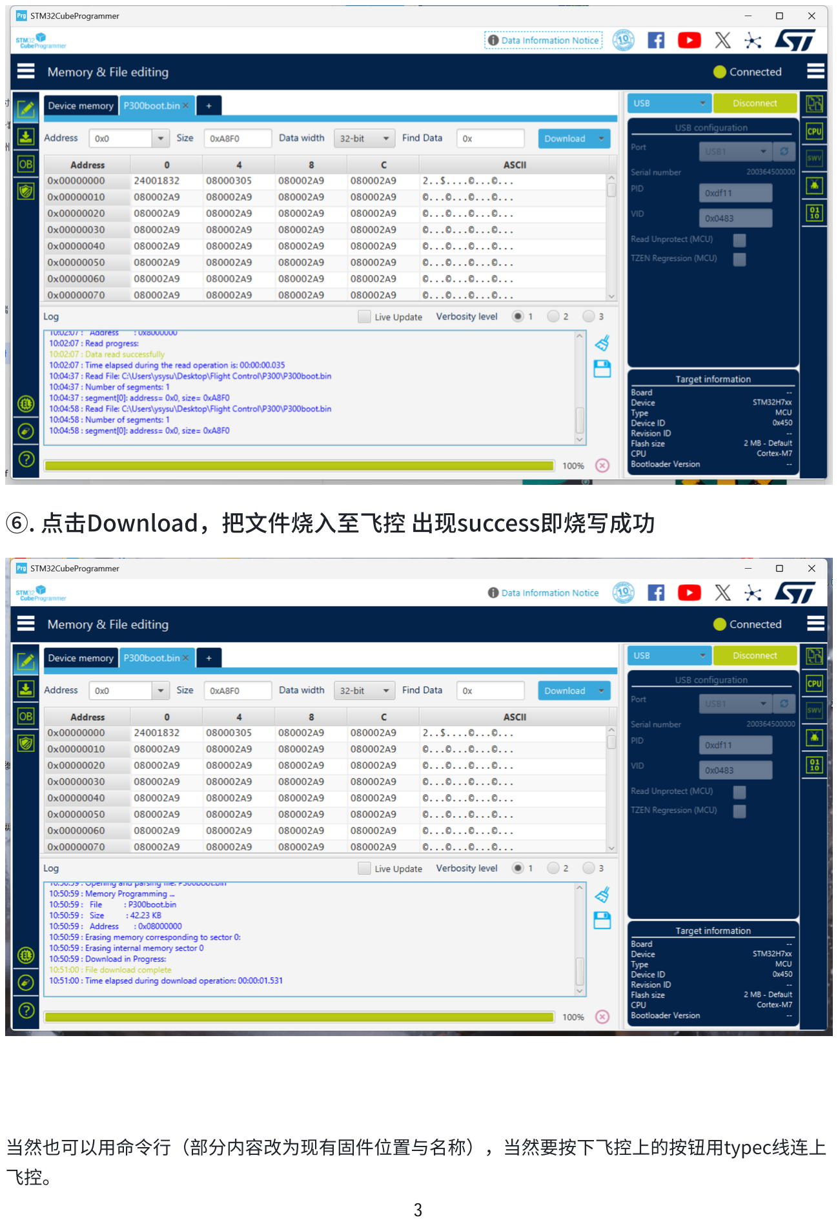
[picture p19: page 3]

### ⑥. 点击Download，把文件烧入至飞控 出现success即烧写成功

当然也可以用命令行（部分内容改为现有固件位置与名称），当然要按下飞控上的按钮用typec线连上 飞控。

dfu-util -a 0 --dfuse-address 0x08000000:force:mass-erase:leave -D ./holybro_kakuteh7mini_bootloader/holybro_kakuteh7mini_bootloader.bin

dfu-util -a 0 --dfuse-address 0x08000000 -D ./holybro_kakuteh7mini_bootloader/holybro_kakuteh7mini_bootloader.bin

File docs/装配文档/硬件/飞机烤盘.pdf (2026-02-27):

# 618飞机烤盘

首先需要准备一个原盘，可以从已经装好的618飞机上拿下来，将源盘（里面有东西的）与目标盘插 入，打开烤盘器，长按按钮5s，松开之后再按2s，之后等待靠完即可。

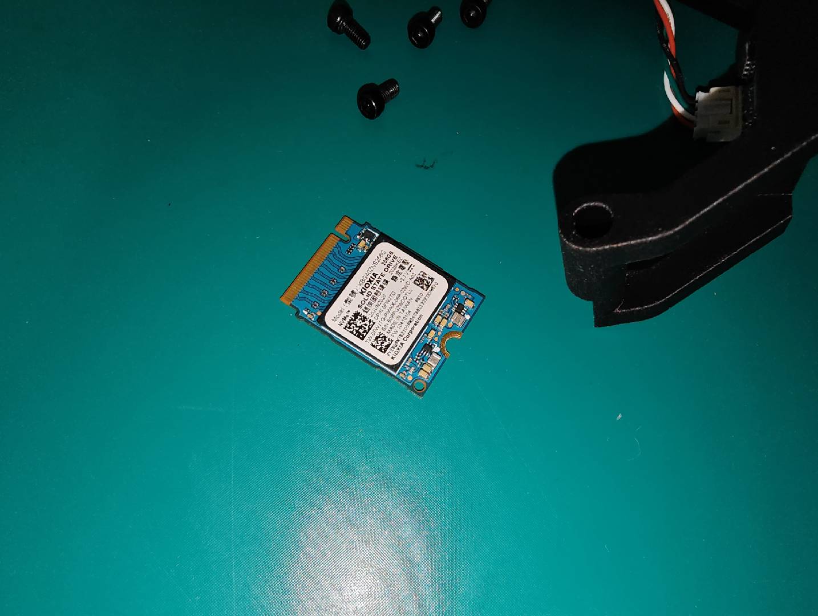
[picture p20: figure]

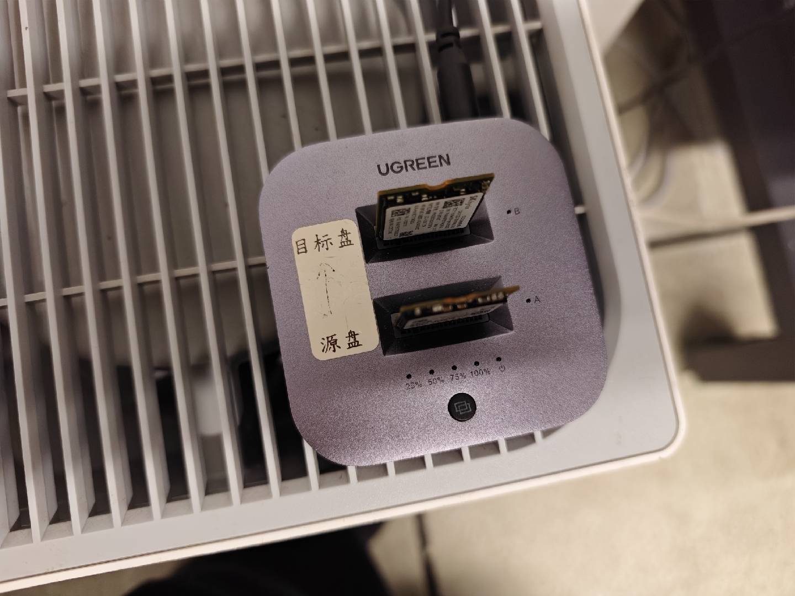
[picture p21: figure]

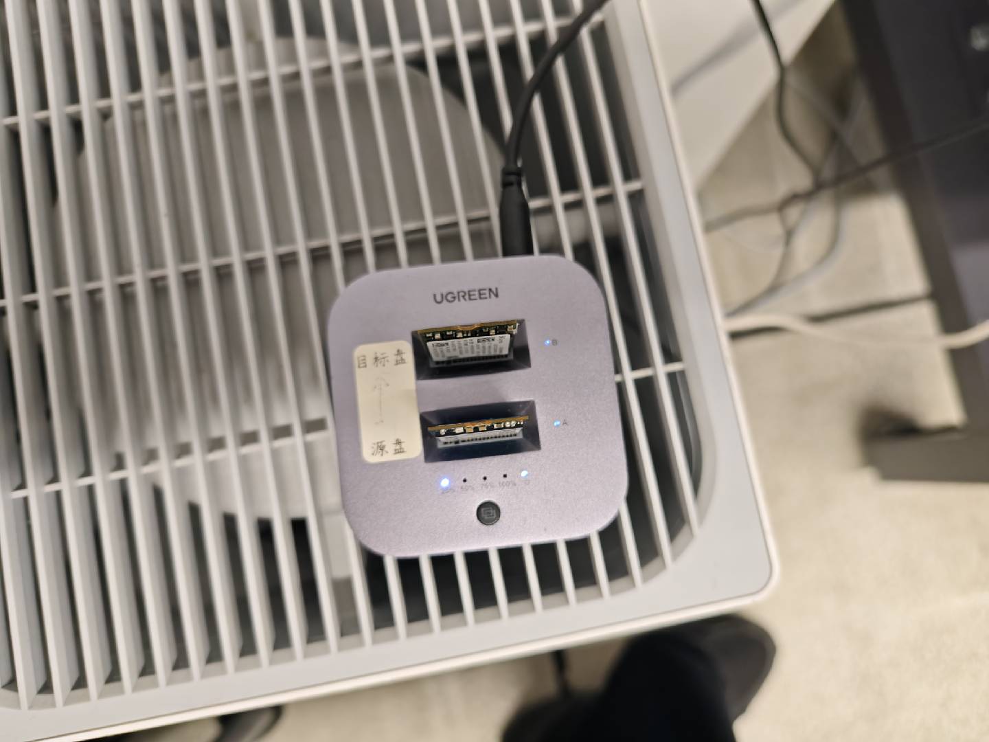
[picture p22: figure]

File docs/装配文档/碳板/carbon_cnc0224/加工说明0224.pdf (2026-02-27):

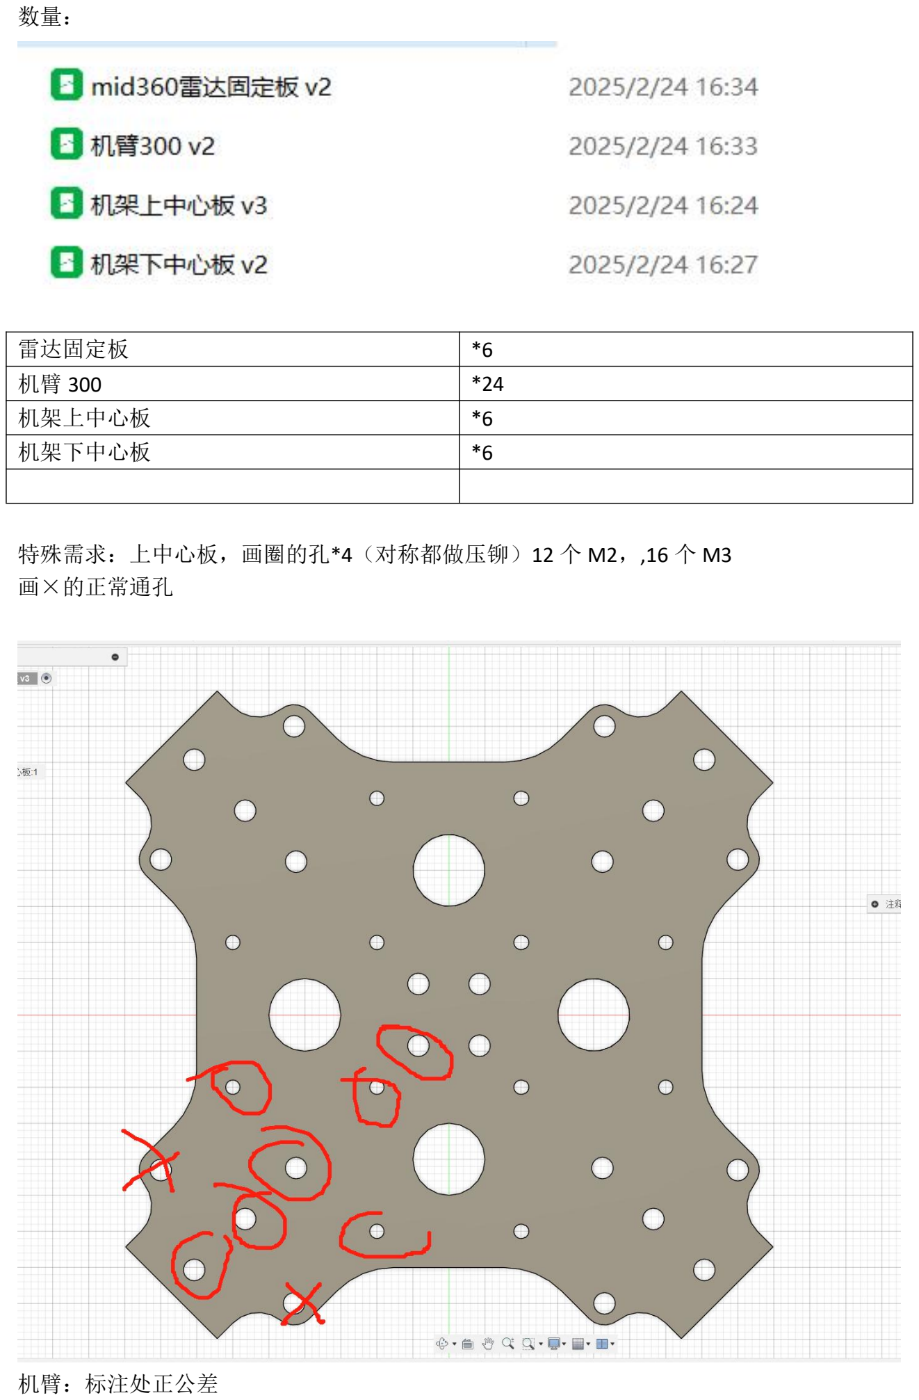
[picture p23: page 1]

数量：

雷达固定板 | *6
机臂 300 | *24
机架上中心板 | *6
机架下中心板 | *6

特殊需求：上中心板，画圈的孔*4（对称都做压铆）12 个 M2，,16 个 M3 画×的正常通孔

机臂：标注处正公差

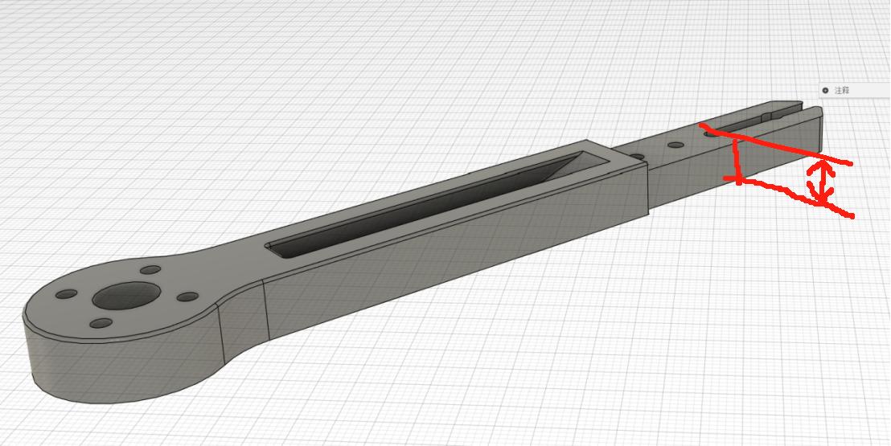
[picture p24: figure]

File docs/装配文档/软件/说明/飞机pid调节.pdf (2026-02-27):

# 618飞机pid调节

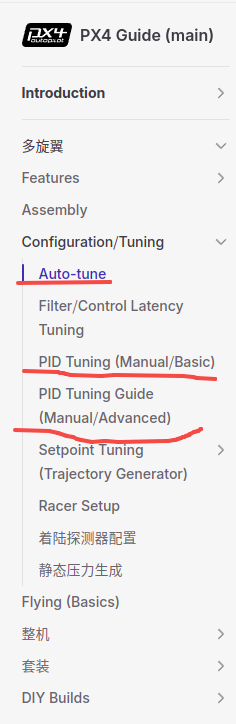
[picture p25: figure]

https://docs.px4.io/main/zh/config/autotune_mc.html

https://docs.ncnynl.com/en/px4/zh/config_mc/pid_tuning_guide_multicopter.html

首先学习上述三个PX4官方文档内容

pid (https://ucno6p0c7gsx.feishu.cn/wiki/Wp9cwTlQ1i4mWgkm2rtc2ZN7n1d)

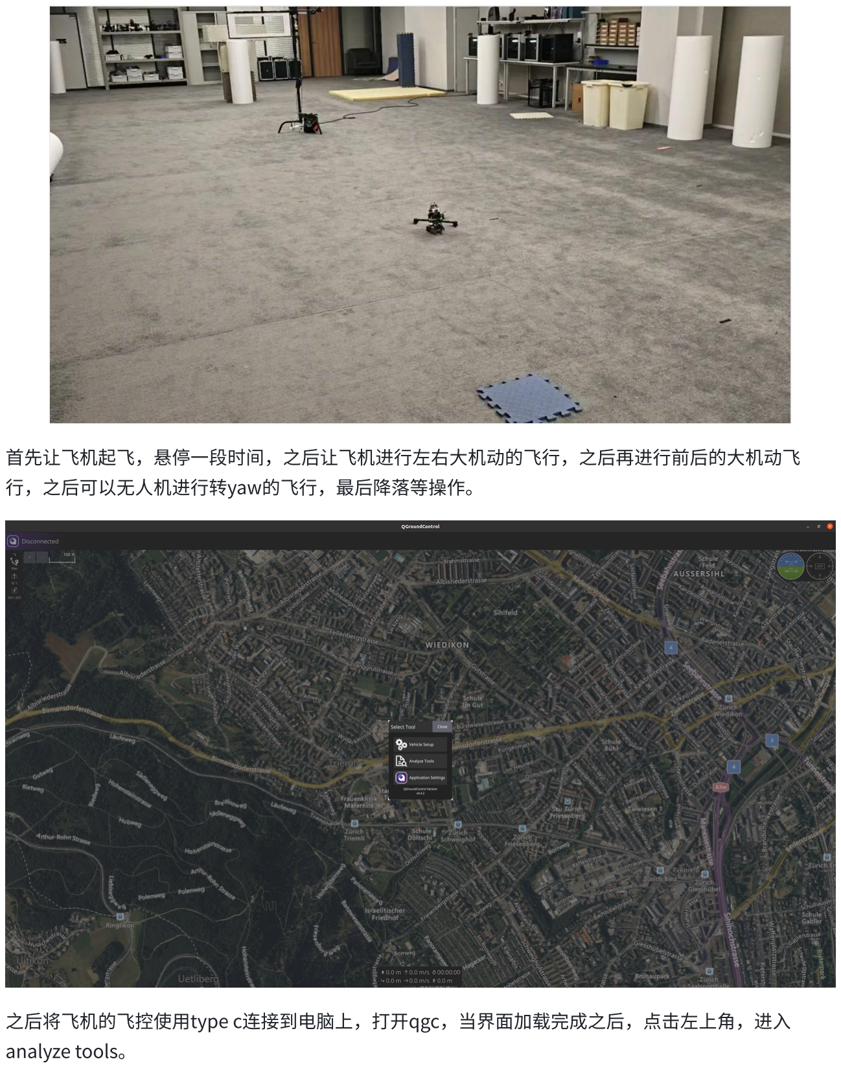
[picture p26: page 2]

首先让飞机起飞，悬停一段时间，之后让飞机进行左右大机动的飞行，之后再进行前后的大机动飞 行，之后可以无人机进行转yaw的飞行，最后降落等操作。

之后将飞机的飞控使用type c连接到电脑上，打开qgc，当界面加载完成之后，点击左上角，进入 analyze tools。

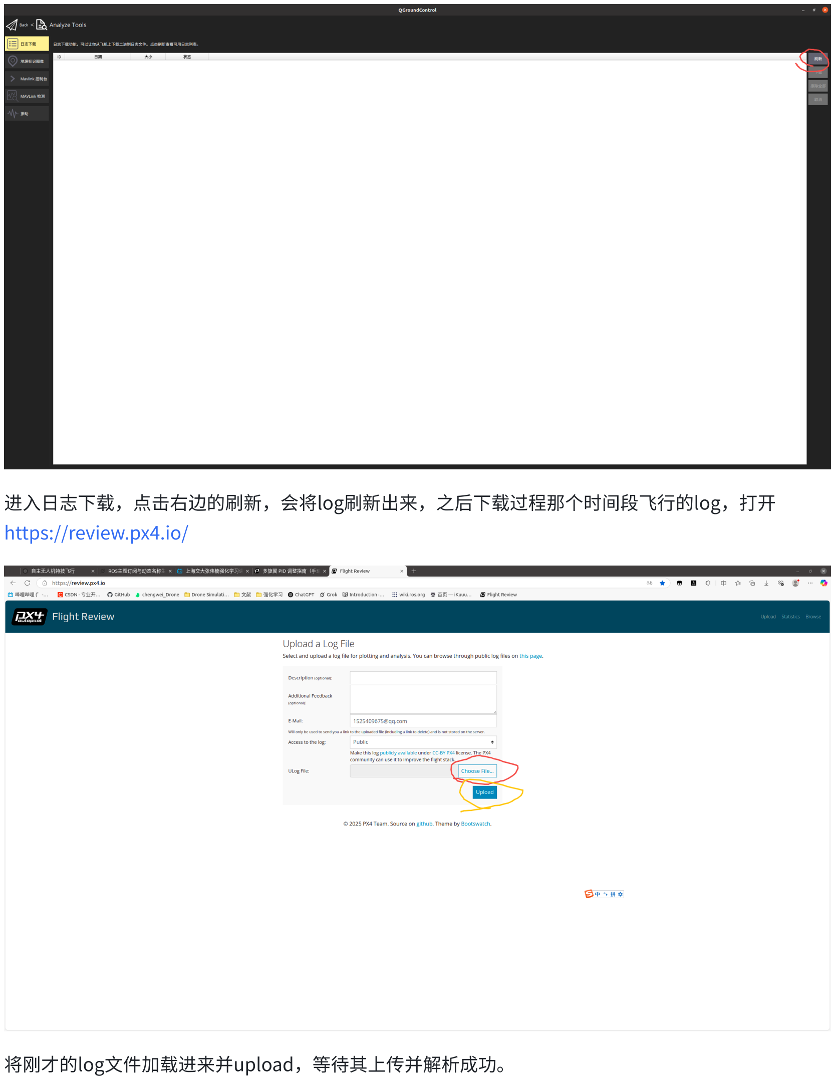
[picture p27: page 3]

进入日志下载，点击右边的刷新，会将log刷新出来，之后下载过程那个时间段飞行的log，打开 https://review.px4.io/

将刚才的log文件加载进来并upload，等待其上传并解析成功。

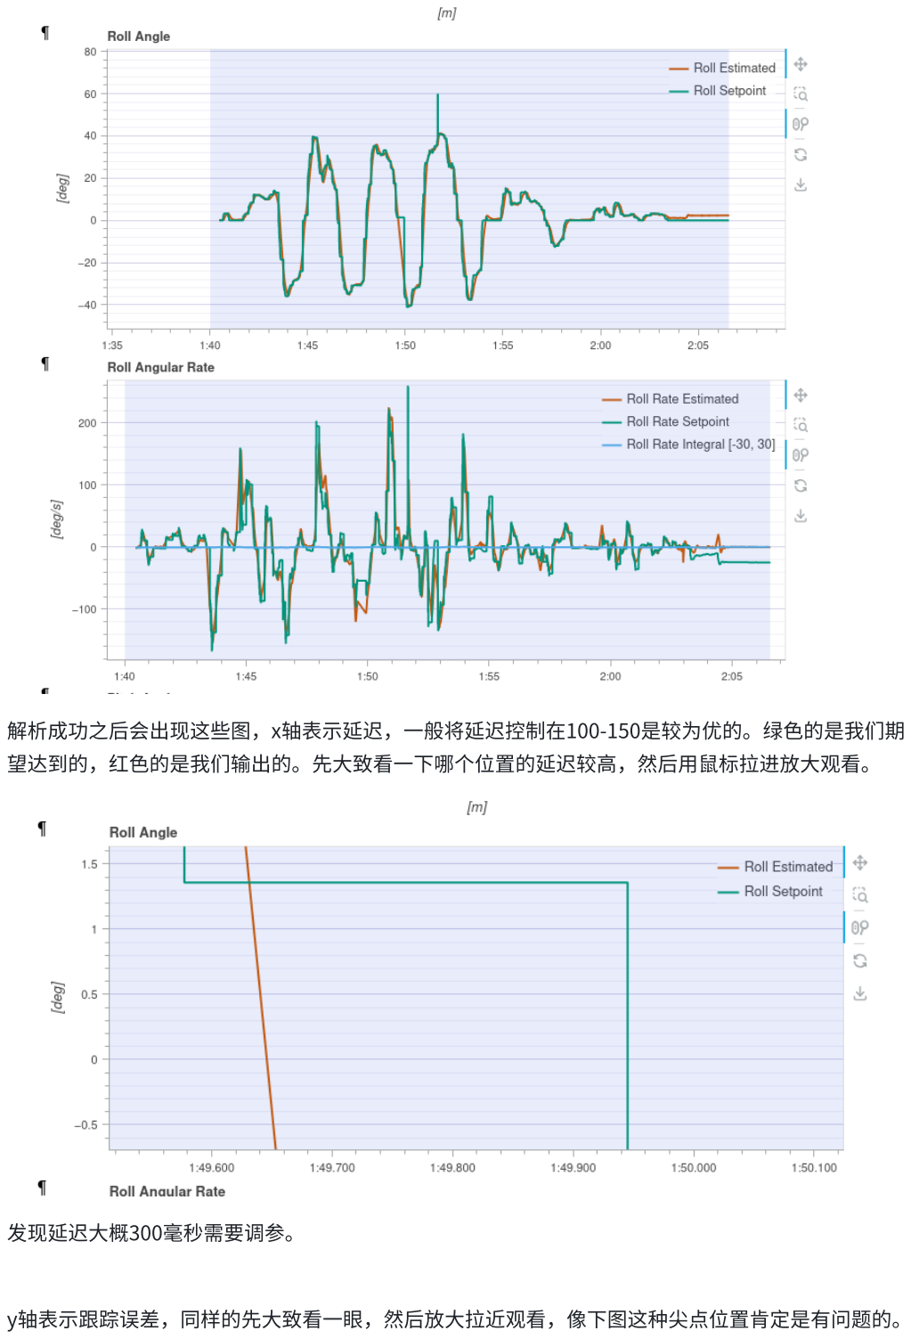
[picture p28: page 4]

解析成功之后会出现这些图，x轴表示延迟，一般将延迟控制在100-150是较为优的。绿色的是我们期 望达到的，红色的是我们输出的。先大致看一下哪个位置的延迟较高，然后用鼠标拉进放大观看。

发现延迟大概300毫秒需要调参。

y轴表示跟踪误差，同样的先大致看一眼，然后放大拉近观看，像下图这种尖点位置肯定是有问题的。

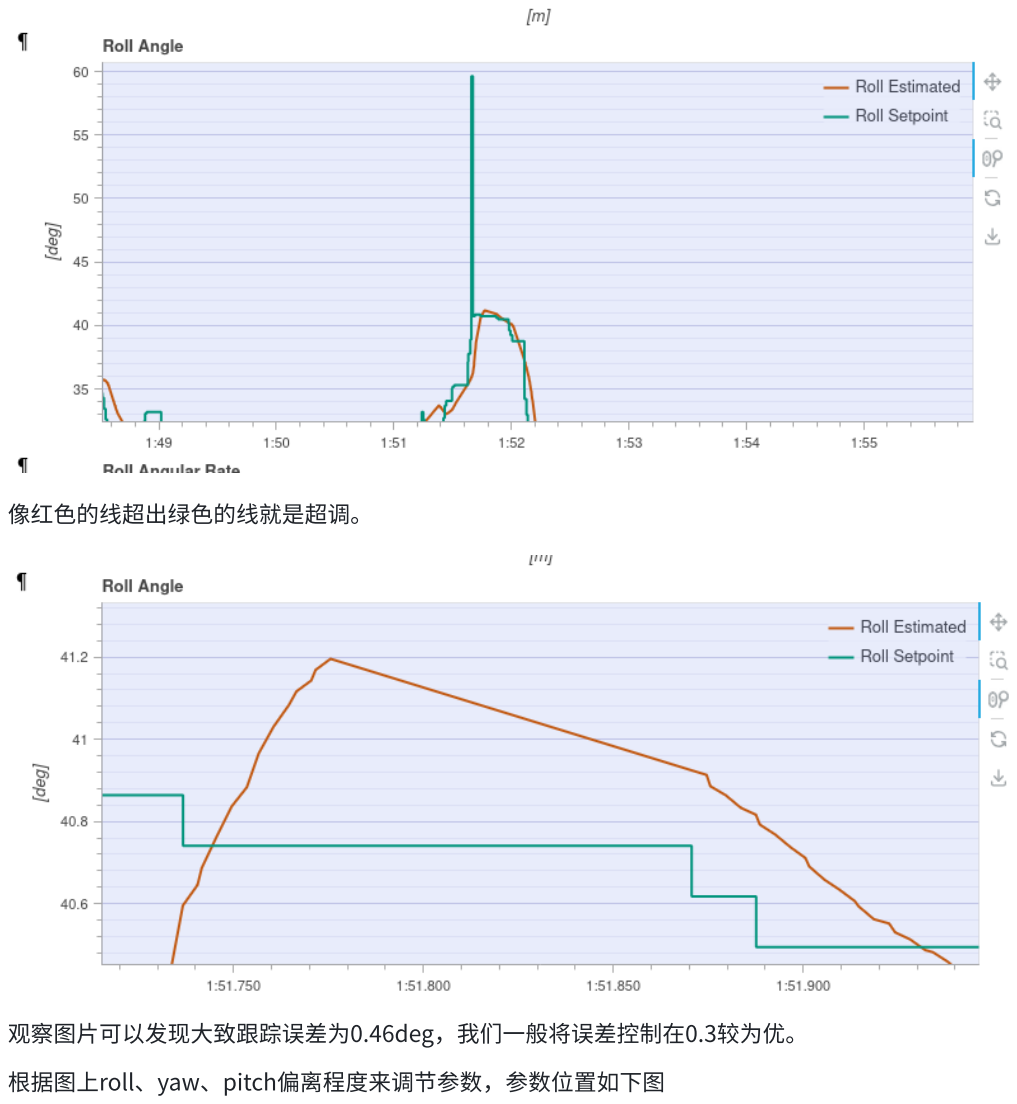
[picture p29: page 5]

像红色的线超出绿色的线就是超调。

观察图片可以发现大致跟踪误差为0.46deg，我们一般将误差控制在0.3较为优。

根据图上roll、yaw、pitch偏离程度来调节参数，参数位置如下图

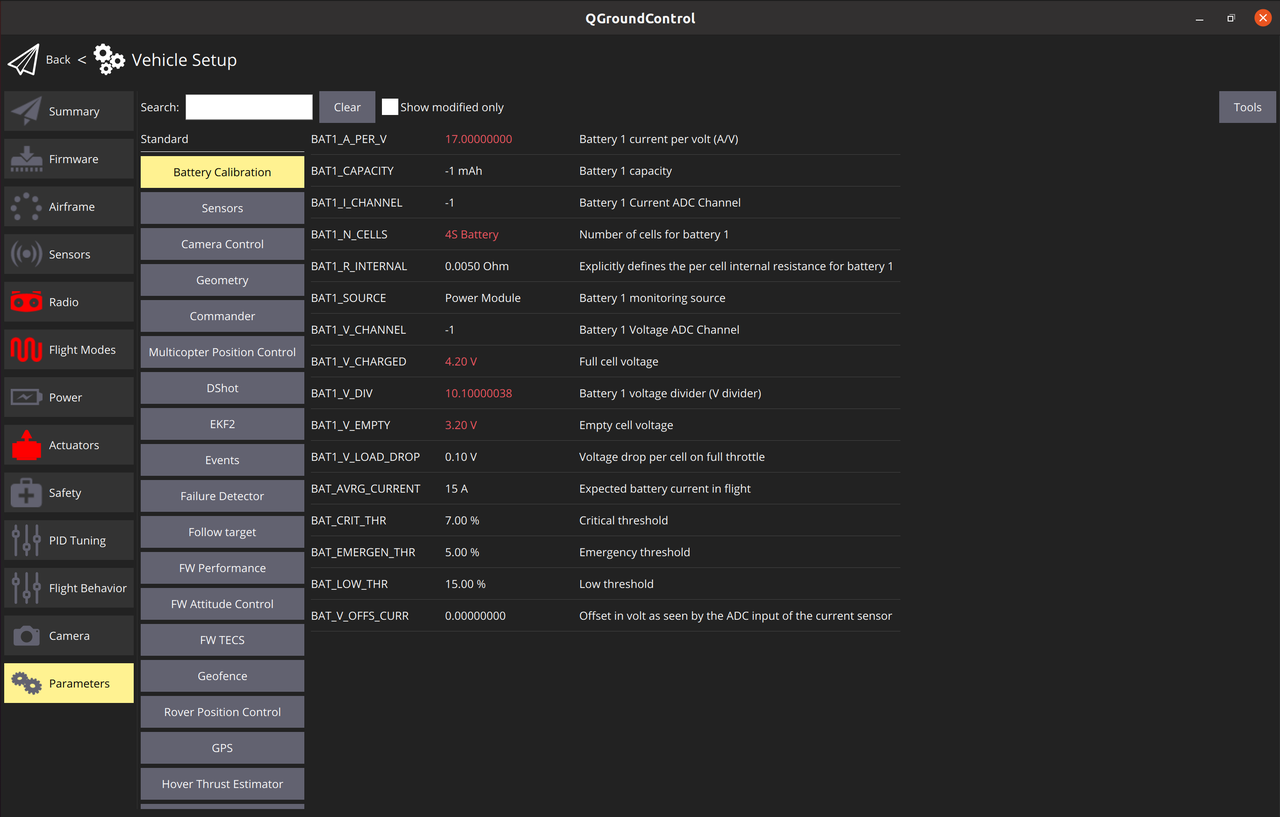
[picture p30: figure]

在搜索栏中搜索需要改的参数，如MC_ROLLRATE_P、 (https://docs.ncnynl.com/en/px4/zh/advanced_config/parameter_reference.html#MC_ROLLRATE_P)MC_ROLLRATE_I、 (https://docs.ncnynl.com/en/px4/zh/advanced_config/parameter_reference.html#MC_ROLLRATE_I)MC_ROLLRATE_D、 (https://docs.ncnynl.com/en/px4/zh/advanced_config/parameter_reference.html#MC_ROLLRATE_D) MC_ROLLRATE_K、 (https://docs.ncnynl.com/en/px4/zh/advanced_config/parameter_reference.html#MC_ROLLRATE_K)MC_ROLL_P (https://docs.ncnynl.com/en/px4/zh/advanced_config/parameter_reference.html#MC_ROLL_P)

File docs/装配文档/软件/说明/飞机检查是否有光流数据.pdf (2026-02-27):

# 618飞机检查是否有光流数据

连接上qgc并给飞机上电，点击analyze tools中的mavlink inspector，找到optical_flow_rad，若有 则说明有光流数据此时可以上下移动无人机观察其distance是否有变化

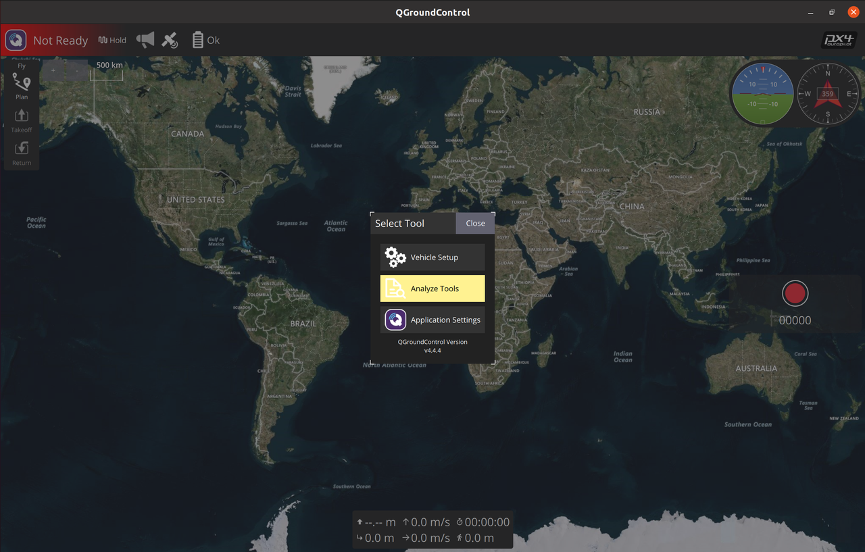
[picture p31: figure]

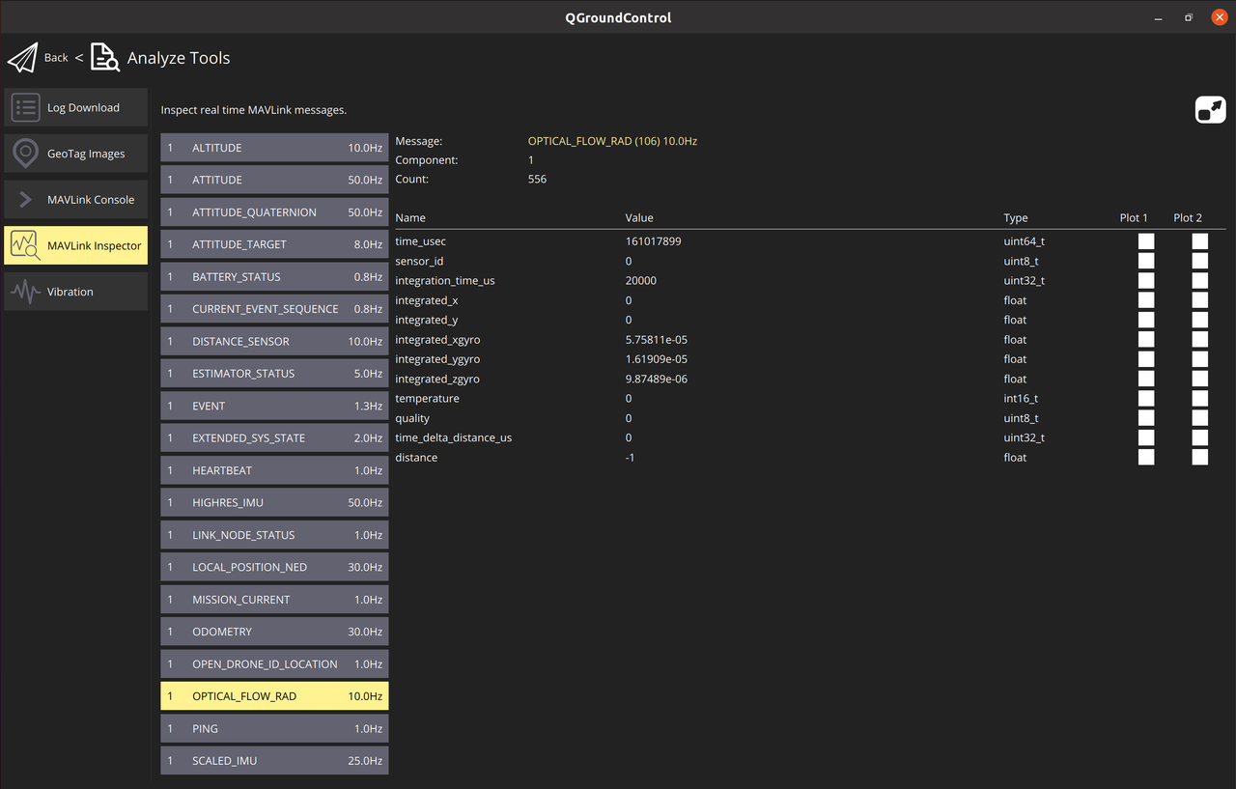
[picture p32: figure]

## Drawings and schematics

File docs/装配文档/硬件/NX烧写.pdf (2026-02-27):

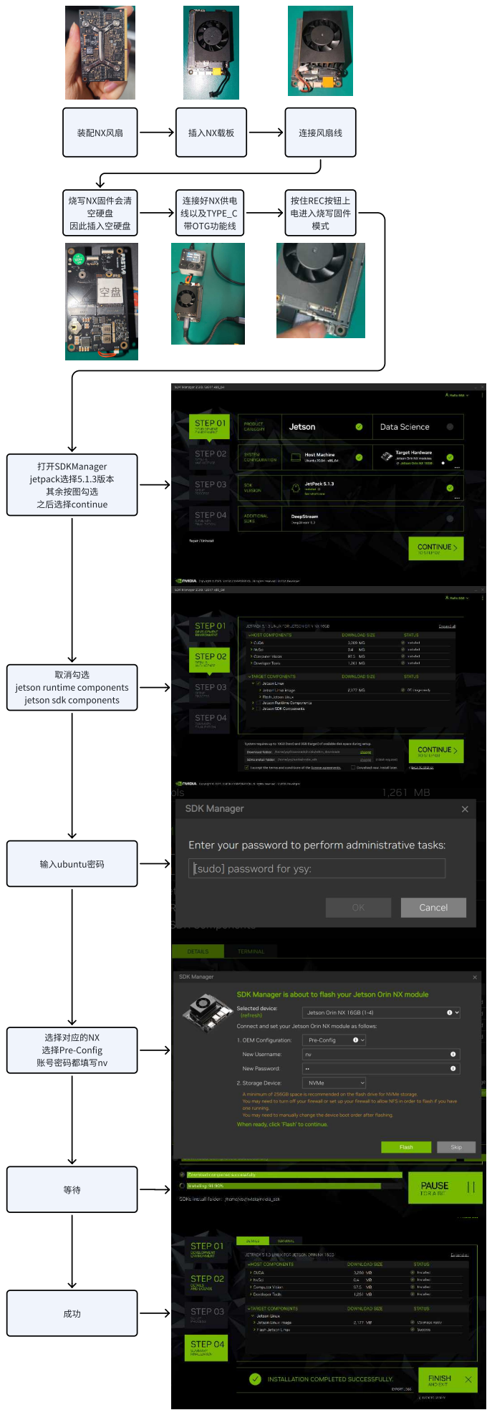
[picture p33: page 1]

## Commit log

2026-02-27 第一次提交：建立基础目录并上传装配文档
    [jsh_wk_lidar300_flow-0418-drone3.params, mid360雷达固定板 v2.step, 工具清单.xlsx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]
2026-02-27 第二次提交：撰写readme
2026-02-28 新增3d建模和部分官方文档
